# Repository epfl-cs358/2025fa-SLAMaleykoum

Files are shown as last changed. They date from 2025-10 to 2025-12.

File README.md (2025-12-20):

# SLAMaleykoum

> An autonomous mobile robot that transforms an RC car into an intelligent mapping and navigation platform using dual ESP32-S3 microcontrollers.

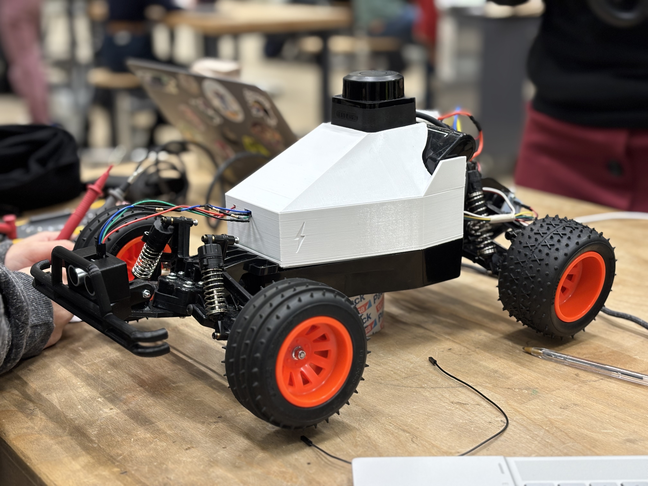
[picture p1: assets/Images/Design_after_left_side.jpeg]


**Live Demo - 19.12.2025**
<p align="center">
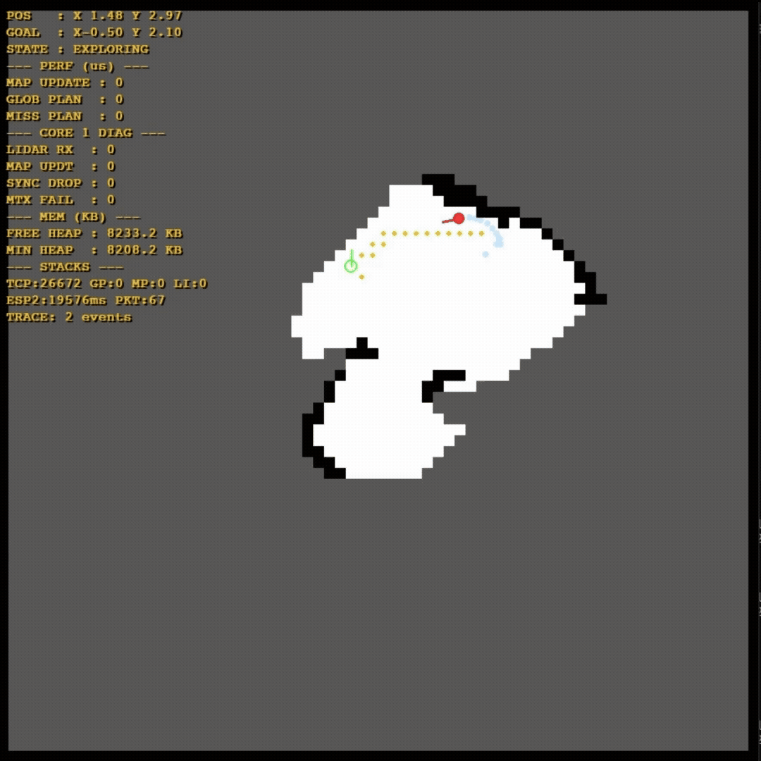
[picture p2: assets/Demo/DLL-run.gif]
  
  
</p>

_Screen recording sped up x3, video in real speed (for reference)_

## Project Context

**Abstract**

SLAMaleykoum aims to implement **Simultaneous Localization and Mapping (SLAM)**, a robotics technique that enables a mobile robot to build a map of an unknown environment while simultaneously tracking its own location within that map. This chicken-and-egg problem requires three core capabilities working in concert:

1. **Mapping**: Building an accurate representation of the environment using LiDAR sensor data processed through a Bayesian occupancy grid with Bresenham ray tracing
2. **Localization**: Determining the robot's position by fusing wheel encoder odometry with IMU orientation data
3. **Navigation**: Planning collision-free paths using A* search on the occupancy grid and executing them with Pure Pursuit trajectory tracking

The system runs entirely on two ESP32-S3 microcontrollers with no external computation, using FreeRTOS for real-time task scheduling. The robot autonomously explores unknown environments, discovers frontiers (boundaries between known and unknown space), and navigates to them while avoiding static and dynamic obstacles detected.

**Course Context:**

This project was developed as part of the [**Making Intelligent Things** (CS-358)](https://edu.epfl.ch/coursebook/en/making-intelligent-things-a-CS-358-A) course at **EPFL** (École Polytechnique Fédérale de Lausanne).

**Acknowledgments:**
- Built upon the physical structrue of [**TurboSLAM**](https://github.com/epfl-cs358/2025sp-turboslam) (previous team)
- Course TAs and [DLL coaches](https://make.epfl.ch/coaches) for guidance and support

**Note on Continued Development:**

Although the CS-358 course has concluded, we continue to actively develop and improve SLAMaleykoum. For current work-in-progress features, planned enhancements, and future research directions, see [Ongoing Works & Next Steps](#ongoing-works--next-steps).

---

## Quick Jump To Detailed Documentation

For in-depth technical details, refer to the dedicated subsystem documentation:

<table>
<tr>
<td width="33%" align="center">

### 🔧 **[Hardware: Step by Step How to build](assets/docs/hardware/ASSEMBLE_GUIDE.md)**

Assembly instructions, wiring diagrams, CAD files, component specs

</td>
<td width="33%" align="center">

### 🗺️ **[ESP-1 Controller: Mapping & Planning](include/esp1/README.md)**

LiDAR processing, Bayesian mapping, frontier detection, A* path planning

</td>
<td width="33%" align="center">

### 🎮 **[ESP-2 Operator: Localization & Driving](include/esp2/README.md)**

Sensor fusion, Pure Pursuit control, motor management, safety systems

</td>
</tr>
</table>

---

## Table of Contents

1. [Project Overview](#project-overview)
2. [Quick Start](#quick-start)
3. [Hardware](#hardware)
4. [System Architecture](#system-architecture)
5. [Software Setup](#software-setup)
6. [Configuration & Tuning](#configuration--tuning)
7. [Documentation Index](#documentation-index)
8. [Archives](#archives)
9. [Ongoing Works & Next Steps](#ongoing-works--next-steps)
10. [Credits](#credits)
11. [Conclusion](#conclusion)

---

## Project Overview

### Vision

SLAMaleykoum is an autonomous robotics platform that transforms a standard RC car chassis into an intelligent mobile robot capable of mapping and navigating unknown environments. The system performs full Simultaneous Localization and Mapping (SLAM), enabling the robot to autonomously explore, build a map, localize itself with high accuracy in real time, navigate to target coordinates, dynamically avoid obstacles, and maintain a reliable estimate of its position throughout the mission.

Here is our original [Project proposal](https://www.overleaf.com/9942875199zgzbkrmgkkkj#3fbbb2) for our SLAM Car. Please note that it represents the initial version of the project. Since then, many aspects have evolved and changed throughout development, so the proposal should be considered an early-stage reference rather than the final design.

### How the Robot "Thinks"

The robot operates through a continuous perception-planning-action loop distributed across two processors:

**High-Level Decision Making (ESP-1 Controller):**
1. **Perceive** - Process LiDAR scans to update the occupancy grid map
2. **Analyze** - Identify frontiers (boundaries between explored and unexplored areas)
3. **Decide** - Select the closest explorable frontier as the next goal
4. **Plan** - Compute a collision-free path to the goal using A* search
5. **Command** - Send path waypoints to the Operator (ESP-2)

**Why this approach?** Frontier-based exploration naturally drives the robot to map the entire environment without human intervention. The robot is "curious" - it always seeks to explore what it doesn't know yet.

**Low-Level Execution (ESP-2 Operator):**
1. **Localize** - Continuously estimate position by fusing encoder and IMU data
2. **Track** - Follow the commanded path using Pure Pursuit controller
3. **React** - Monitor ultrasonic sensor for obstacles; emergency stop if needed
4. **Report** - Send updated position back to Controller for map correction

**Why this split?** The Controller handles computationally expensive tasks (mapping, pathfinding) at lower rates (1-10 Hz), while the Operator focuses on time-critical control loops at high rates (50-100 Hz). This separation ensures smooth, responsive driving even while planning is ongoing.

### Technical Vocabulary

- **ESP** (ESP32-S3): Microcontroller with dual-core processor and WiFi
- **ESC** (Electronic Speed Controller): Motor driver that converts PWM signals to motor power
- **LiDAR** (Light Detection and Ranging): Laser-based distance sensor for environment scanning
- **IMU** (Inertial Measurement Unit): Sensor measuring orientation and acceleration
- **I2C** (Inter-Integrated Circuit): Serial communication protocol for sensors
- **UART** (Universal Asynchronous Receiver-Transmitter): Serial communication between ESPs
- **TCP** (Transmission Control Protocol): Network protocol used for ground station communication
- **GS** (Ground Station): External computer for visualization (monitoring only)

### Key Objectives

- **Autonomous Mapping**: Create detailed environment maps using LiDAR sensor data
- **Robust Localization**: Maintain accurate position estimation through sensor fusion
- **Intelligent Navigation**: Plan and execute collision-free paths to destinations
- **Real-time Control**: Execute precise motor control for path following
- **Remote Monitoring**: Provide GS visualization

> **Important**: The car should be able to operate fully autonomously → with **no** GS.
> No computations nor storage will be offloaded to the GS.

### Core Technologies

- **Hardware**: Dual ESP32-S3 microcontrollers, LiDAR sensor, wheel encoders, IMU
- **Operating System**: [FreeRTOS](https://www.freertos.org/) for real-time multitasking and priority-based scheduling
- **Communication**: UART (inter-processor), TCP (ground station)
- **Algorithms**: 
  - [A* pathfinding](https://en.wikipedia.org/wiki/A*_search_algorithm) - Optimal graph search algorithm
  - [Pure Pursuit](https://www.ri.cmu.edu/pub_files/pub3/coulter_r_craig_1992_1/coulter_r_craig_1992_1.pdf) controller - Path tracking for car-like robots
  - [Bresenham's line algorithm](https://en.wikipedia.org/wiki/Bresenham%27s_line_algorithm) - Efficient grid ray tracing
  - [BFS](https://en.wikipedia.org/wiki/Breadth-first_search) (Breadth-First Search) - Frontier clustering
  - [Bayesian occupancy grid mapping](https://ieeexplore.ieee.org/document/30720) - Probabilistic environment representation

### System at a Glance

```
┌─────────────────────────────────────────────────────────┐
│  ESP-1 CONTROLLER: Mapping & Planning (1-10 Hz)         │
│  • LiDAR processing & Bayesian mapping                  │
│  • Frontier detection & clustering                      │
│  • A* global path planning                              │
│  • Ground station telemetry (WiFi/TCP)                  │
└─────────────────────────────────────────────────────────┘
                         ↕ UART
┌─────────────────────────────────────────────────────────┐
│  ESP-2 OPERATOR: Localization & Driving (50-100 Hz)     │
│  • Sensor fusion (encoder + IMU)                        │
│  • Pure Pursuit path following                          │
│  • Motor & steering control                             │
│  • Emergency obstacle handling                          │
└─────────────────────────────────────────────────────────┘
```

---

## Quick Start

### Prerequisites Checklist

**Hardware:**
- Assembled robot (see [Hardware section](#hardware))
- 9.0V NiMH battery (charged)
- USB-C cables for flashing ESP32s
- Computer with WiFi capability (for visualization)

**Software:**
- [Python 3.8+](https://www.python.org/downloads/)
- [PlatformIO Core](https://docs.platformio.org/en/latest/core/index.html) or VS Code extension ([install guide](https://docs.platformio.org/en/latest/core/index.html))

### Flash & Run

**Step 0: Clone the Repository**
```bash
git clone https://github.com/epfl-cs358/2025fa-SLAMaleykoum.git
cd 2025fa-SLAMaleykoum
```

**Step 1: Install Ground Station Dependencies**
```bash
# Create virtual environment
python3 -m venv slamaleykoum_venv

# Activate environment
source slamaleykoum_venv/bin/activate  # On Windows: slamaleykoum_venv\Scripts\activate

# Install dependencies
pip install -r requirements.txt
```

**Step 2: Flash ESP32 Firmware**

This project uses two ESP32s. You must flash them individually.

```bash
# In VS Code with PlatformIO extension:
# 1. Connect ESP1 via USB (use RIGHT port - left port may not work)
# 2. Open PlatformIO extension (alien icon)
# 3. Click esp1/General/Upload
# 4. Wait for upload to complete
# 5. Repeat for ESP2: Connect ESP2 → esp2/General/Upload
```

**Step 3: Power Up & Connect**

1. **Power sequence:**
   ```
   Battery → ESC → Turn ESC switch ON
   ```
   ⚠️ **WARNING**: When disconnecting, first turn the ESC off, then disconnect the battery.

2. **Connect to robot WiFi:**
   - **SSID:** `LIDAR_AP`
   - **Password:** `l1darpass`

3. **Launch ground station:**
_Note: Further documentation can be found [here](assets/docs/GROUND_STATION.md)_
   ```bash
   # Ensure your venv is active
   source slamaleykoum_venv/bin/activate
   
   # Run the interface
   python ground_station.py
   ```
   A *Pygame* window will appear. Press **START** to begin logging data and visualizing the real-time LIDAR feed.

**What to expect:**
- Ground station shows live LiDAR scan
- Robot begins mapping and moving toward frontiers
- Map builds progressively as robot explores

**First-time issues?** → Check out [Troubleshooting guide](assets/docs/troubleshooting.md)

> *Dev Note: To change WiFi credentials, modify [`src/esp1/main_esp1.cpp`](src/esp1/main_esp1.cpp) before flashing.*

---

## Hardware

### Component List

| Component | Reference Links | Price (CHF) |
|---|---|---|
| Tamiya Blitzer Beetle | [Manual](https://www.tamiyausa.com/media/files/58502ml-829-5367.pdf) | 129.00 |
| RPLIDAR C1 | [Datasheet](https://d229kd5ey79jzj.cloudfront.net/3157/SLAMTEC_rplidar_datasheet_C1_v1.0_en.pdf), [SDK](https://github.com/Slamtec/rplidar_sdk), [Wiki](https://www.waveshare.com/wiki/RPLIDAR_C1) | 79.90 |
| ESP32-S3-WROOM-1 Microcontroller (x2)  | [Datasheet](https://cdn-shop.adafruit.com/product-files/5477/esp32-s3_datasheet_en.pdf) | 50.90 |
| DMS15 Servo | [Wiki](https://wiki.dfrobot.com/DSS-M15S_270%C2%B0_15KG_DF_Metal_Servo_with_Analog_Feedback_SKU__SER0044) | 5.00 |
| BNO086 IMU | [Datasheet](https://docs.sparkfun.com/SparkFun_VR_IMU_Breakout_BNO086_QWIIC/assets/component_documentation/BNO080_085-Datasheet_v1.16.pdf) | 19.90 |
| AS5600 Encoder | [Datasheet](https://files.seeedstudio.com/wiki/Grove-12-bit-Magnetic-Rotary-Position-Sensor-AS5600/res/Magnetic%20Rotary%20Position%20Sensor%20AS5600%20Datasheet.pdf) | 12.90 |
| HC-SR04 Ultrasonic Sensor | [Datasheet](https://handsontec.com/dataspecs/sensor/SR-04-Ultrasonic.pdf) | 2.00 |
| 540J Motor | [Datasheet](https://asset.conrad.com/media10/add/160267/c1/-/en/001385115DS01/adatlap-1385115-540-es-motor-reely-532114c.pdf) | — |
| THW-1060-RTR ESC | [Datasheet](https://www.hobbywing.com/en/uploads/file/20221015/f60b7ebe160a7b283927ae8916d36763.pdf) | — |
| LM2596 Buck Converter | [Datasheet](https://www.ti.com/lit/ds/symlink/lm2596.pdf) | 5.90 |
| 7.2V Battery | [Product Page](https://www.galaxus.ch/fr/s5/product/gens-ace-modelisme-dune-batterie-720-v-5000-mah-batterie-rc-9459930) | 32.90 |
| **Total Cost** | | **338.4**  |

**Additional materials needed:**
- $3 \times 1 K\Omega$ resistors (for the ultrasonic sensor voltage divider)
- Assorted jumper cables and connectors (male/female)
- Heat-shrink tubing or insulation sleeves
- Soldering kit (soldering iron, solder wire)
- Hot air/heat gun (for shrinking tubing)
- Screw set (M3 and M6 as used in mounts)

### Assembly Overview
Clicky link: [Full Step-by-step Assembly guide here](/assets/docs/hardware/ASSEMBLE_GUIDE.md)

The robot is built on a Tamiya Blitzer Beetle chassis with custom 3D-printed mounts for the LiDAR, ESP32 boards, encoder, ultrasonic sensor, and battery. Assembly is straightforward: build the base chassis, install the encoder and magnet on the motor shaft, mount the electronics platform, attach the sensors, and finish with wiring.

**Assembly phases:**
1. **Chassis** - Build base chassis & install motor/encoder
2. **3D-printed mounts** - Install LiDAR platform, ESP32 holders, sensor brackets
3. **Electronics mounting** - Secure ESPs, buck converter, IMU
4. **Wiring** - Follow electrical diagram, install voltage divider
5. **Final assembly** - Install battery, route cables, verify connections

**📘 Full step-by-step assembly guide (with photos, CAD files, wiring diagrams):**  
→ [**Complete Assembly Instructions**](/assets/docs/hardware/ASSEMBLE_GUIDE.md)

### Wiring & Electrical

Clicky link: [Full wiring explanation HERE](/assets/docs/hardware/circuit/README.md)

**Electrical Diagram:**

<p align="center">
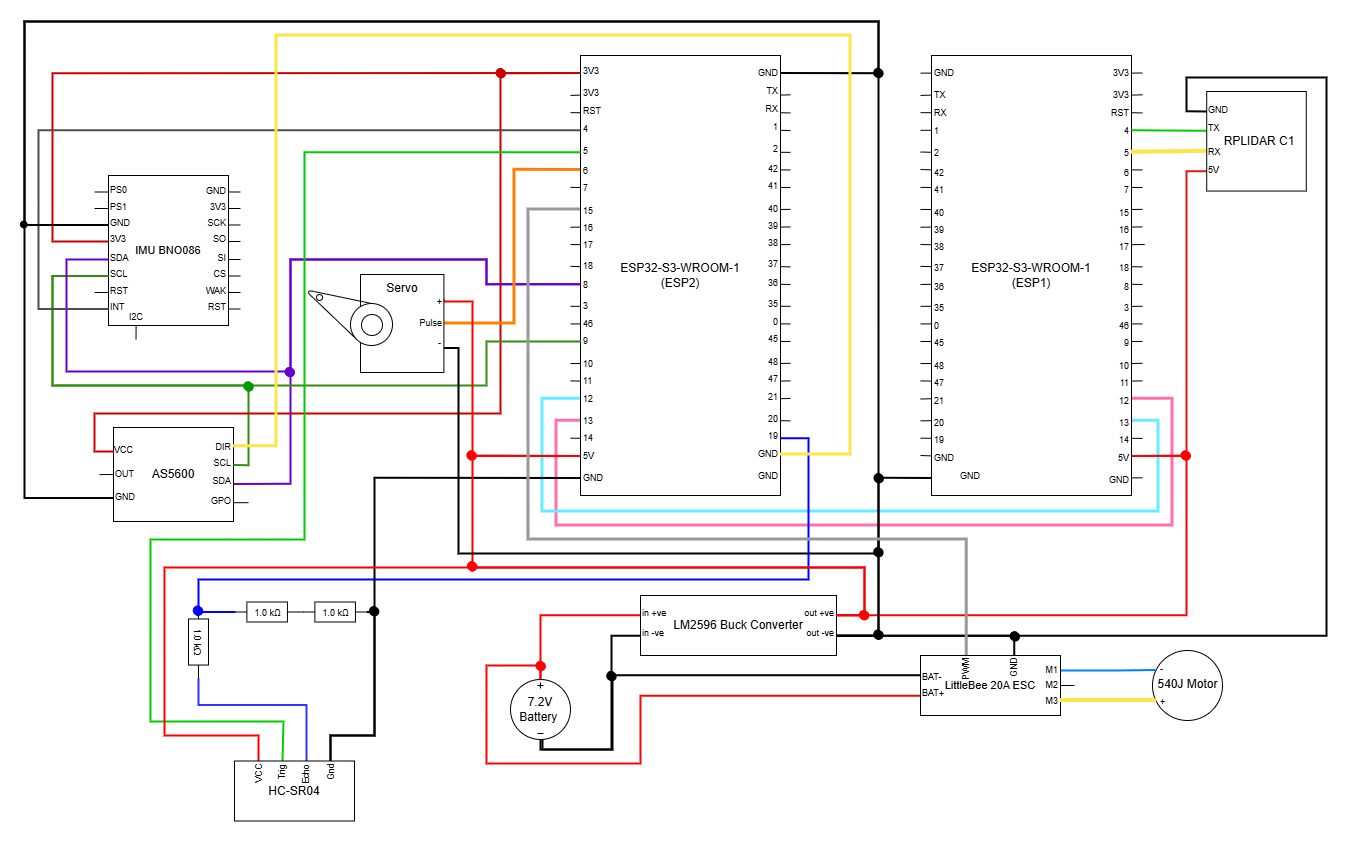
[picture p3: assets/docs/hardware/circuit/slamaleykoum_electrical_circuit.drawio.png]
Electrical Circuit
  
</p>

**⚠️ Important Wiring Notes (Do Not Skip)**

- **Common Ground**: All components (ESP32s, ESC, sensors, servo) must share a common ground from the buck converter.

- **5V vs 3.3V Power**:
  - ESP32 boards, ultrasonic sensor, lidar, and servo are powered from 5V (buck converter)
  - IMU and encoder are powered from ESP2's 3.3V pin

- **Ultrasonic Sensor (HC-SR04) → Voltage Divider Required**
  - The HC-SR04 ECHO pin outputs 5V
  - ESP32 GPIOs are 3.3V-only
  - A resistor voltage divider is mandatory on the ECHO line
  - Connecting ECHO directly to the ESP32 will damage the GPIO

- **ESP-to-ESP Communication**: UART cross-connection is required (TX ↔ RX between ESP1 and ESP2).

**📘 Detailed Wiring & Soldering Guide:**  
→ [**Full wiring explanation**](/assets/docs/hardware/circuit/README.md)

### CAD Files

You can explore all STL files directly in the [**CAD folder**](/assets/CAD).

Here is a quick video of the car's body and roof: [**CAD Video**](/assets/docs/hardware/CAD/fast_cad_video.mp4)



**Note:** The CAD files for the **front bumper**, **ultrasonic sensor case**, and **encoder mount** were originally designed by the group from whom we inherited the car, [**TurboSLAM**](https://github.com/epfl-cs358/2025sp-turboslam).

**Before implementing the hardware setup**, check the [Problems and Recommendations](assets/docs/troubleshooting.md) section (Hardware parts) to get a full scope of what may need to be modified.

---

## System Architecture

The computational load is divided between two ESP32-S3 microcontrollers with clearly defined roles:

- **ESP-1 (Controller)**: High-level perception and planning
- **ESP-2 (Operator)**: Low-level control and execution

We use **FreeRTOS** to enable parallel task execution with priority-based scheduling, ensuring time-critical control loops run reliably while computationally expensive planning tasks run in the background. Inter-processor communication happens via **UART** serial links.

**Rationale:**

1. **Performance**: Each processor focuses on its task without competing for resources
2. **Modularity**: Components are well-isolated, making testing and debugging easier
3. **Reliability**: Control loop continues operating even if global planning encounters issues
4. **Efficiency**: Only essential data is sent from one ESP to the other, limiting information flow
5. **Parallelism**: FreeRTOS allows multiple tasks with different priorities to run concurrently on each dual-core ESP32

*Note: For each ESP we've got a dedicated README file delving into more details. They can be found in [`include/esp1/README.md`](include/esp1/README.md) and [`include/esp2/README.md`](include/esp2/README.md)*

### Architecture Diagrams

**ESP-1 System Diagram:**
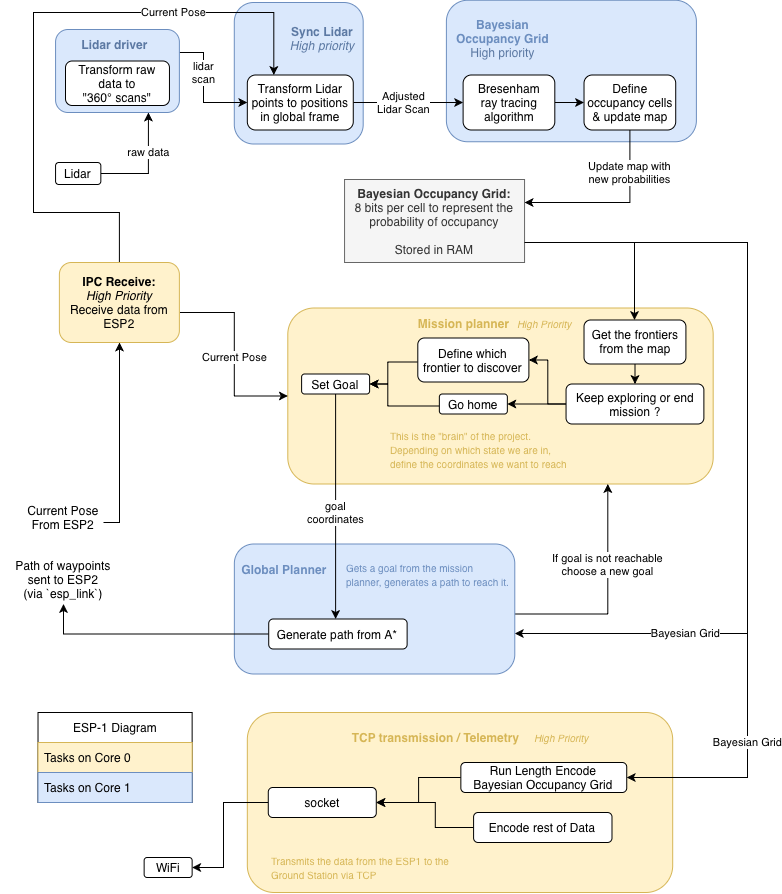
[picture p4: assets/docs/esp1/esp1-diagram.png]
ESP-1 Architecture


**ESP-2 System Diagram:**
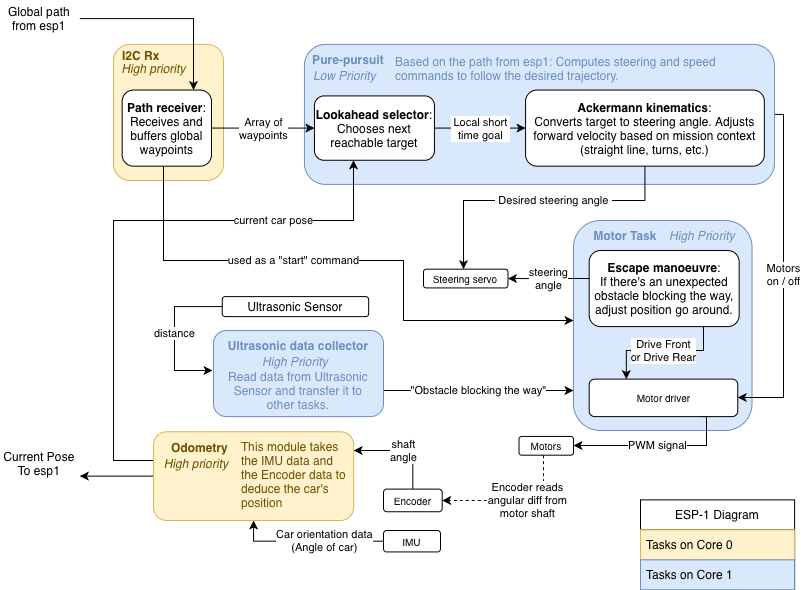
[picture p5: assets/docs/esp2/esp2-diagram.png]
ESP-2 Architecture


### ESP-1 Controller: Mapping & Planning

🦄 **[Full ESP-1 Documentation →](include/esp1/README.md)**

**Primary Mission**: Create and maintain a global understanding of the environment and plan high-level navigation strategies.

**Core Responsibilities**:
- Generate and maintain occupancy grid maps using Bayesian updates
- Find the frontier cells to explore and cluster them using BFS algorithms
- Define a temporary goal for the car to reach
- Plan global paths using A* algorithm
- Share telemetry with ground station via WiFi (visualization purposes)
- Send the computed path to ESP-2

**Key Components:**
- **LiDAR Processing**: Extract and convert RPLIDARC1 data into readable scans
- **Bayesian Grid Mapping**: Build persistent 2D occupancy grid from LiDAR data
- **Mission Planner**: Select exploration goals based on frontier detection
- **Global Planner (A*)**: Compute collision-free paths on the grid

**Operating Frequency**: 1-10 Hz

### ESP-2 Operator: Localization & Motion Control

🦄 **[Full ESP-2 Documentation →](include/esp2/README.md)**

**Primary Mission**: Execute precise vehicle control and maintain high-frequency local position tracking.

**Core Responsibilities**:
- Execute Pure Pursuit path following algorithm
- Handle emergency stop commands and maneuvers to escape when stuck
- Aggregate sensor data (odometry, IMU) to track the position of the car and forward to ESP-1

**Key Components:**
- **Sensor Fusion**: Combine encoder + IMU for pose estimation
- **Pure Pursuit Controller**: Local path-tracking with bicycle model
- **Motor Control**: ESC PWM control with emergency stop
- **Safety System**: Ultrasonic-based obstacle detection
- **Recovery Maneuvers**: Automated escape sequences when blocked

**Operating Frequency**: 50-100 Hz

### Communication Architecture

#### Inter-ESP Communication (UART)

**Protocol**: Custom packet-based with checksums

**Data Flow:**

| Direction | Message Type | Content |
|---|---|---|
| ESP-2 → ESP-1 | `Pose2D` | Current car's position (x, y, θ) |
| ESP-1 → ESP-2 | `PathMessage` | Global path waypoints |

👉 **[Full ESP Link Protocol Documentation →](include/common/esp_link_readme.md)**

#### Ground Station Communication (WiFi/TCP)
🦄 **[Full GS Documentation →](include/esp2/README.md)**

**WiFi Mode**: Access Point (AP)
```
SSID:     LIDAR_AP
Password: l1darpass
```

**ESP-1 → Ground Station**:
- Real-time map visualization data
- Mission status: goal and state
- Robot pose and trajectory
- Telemetry logs

The ESP1 creates a Wi-Fi access point (AP) that we connect to for **monitoring purposes only**. We used MQTT at first to get feedback during tests, but quickly switched to TCP, as it supports higher data throughput.
We additionally log the CPU profiling for the esp1 for debugging pourpuses. Detailed information: [CPU Profiling Documentaiton](assets/docs/debugging/CPU_PROFILING.md)

If you want to establish the same MQTT connection to debug, here is the guide to follow: [**WiFi and MQTT connection guide**](/assets/docs/WiFi_and_MQTT_Connection_Guide___SLAMaleykoum.pdf).

### Shared Mechanisms (`common/`)

- `data_types.h`: Definitions of shared data structures
- `esp_link.h`: The communication system from one ESP to the other. [→ ESP Link README](include/common/esp_link_readme.md)
- `transforms.h`: Functions that transform the position of the robot to the grid and the other way around. [→ Transforms README](include/common/transforms_readme.md)
- `utils.h`: Regroups the functions used across different files to avoid redefining it.
- `wifi_connection.h`: Protocol to connect the WiFi for MQTT

---

## Software Setup

### Development Environment

**Prerequisites:**
* [Python 3.8+](https://www.python.org/downloads/)
* [PlatformIO Core](https://docs.platformio.org/en/latest/core/index.html) or VS Code extension

### Project Structure
```
SLAMaleykoum/
├── include/                    # Header files
│   ├── common/                 # Shared utilities & communication
│   ├── esp1/                   # Mapping & Planning headers
│   └── esp2/                   # Localization & Control headers
│
├── src/                        # Implementation files
│   ├── common/                 # Shared utilities
│   ├── esp1/                   # ESP-1 source code
│   └── esp2/                   # ESP-2 source code
│
├── assets/                     # Documentation & media
│   ├── Demo/                   # Demo videos
│   ├── Images/                 # Photos & diagrams
│   └── docs/                   # Technical documentation
│       ├── hardware/           # Assembly guide, CAD files, wiring
│       ├── esp1/               # Architecture diagrams
│       └── esp2/               # Architecture diagrams
│
├── archives/                   # Historical deprecated implementations
│
├── README.md
├── requirements.txt            # Set up python requirements
├── ground_station.py           # Visualization & telemetry
├── platformio.ini              # Build configuration
└── boards/                     # Custom board definitions
```

**Key Directories:**
- `include/` + `src/` - Dual-ESP codebase organized by subsystem
- `assets/` - All documentation, images, and demo videos
- `archives/` - Previous implementations and test code

### Ground Station (PC)

The ground station script runs on your computer to visualize telemetry.  
*Note: We recommend using a virtual environment.*

Install the dependencies from our `requirements.txt` file.

```bash
# Create virtual environment
python3 -m venv slamaleykoum_venv

# Activate environment
source slamaleykoum_venv/bin/activate  # On Windows: slamaleykoum_venv\Scripts\activate

# Install dependencies
pip install -r requirements.txt
```

### Firmware (ESP32s)

This project uses two ESP32s. You must flash them individually.

**Upload Code:**

Open in PlatformIO: Open the project folder in VS Code.

1. Connect to the ESP1 via USB.
2. Open the *platformio* extension in VS Code (the alien icon).
3. Click on `esp1/General/Upload`.
4. Repeat for the ESP2: Connect ESP2 → `esp2/General/Upload`.

**⚠️ Important:** Use the **RIGHT USB port** on each ESP32. Left ports don't seem to work for programming.
*Note: In our design, the esp1 is upside down, so the right port is the one on the left looking from the outside of the car.*

### WiFi Configuration

**Default credentials** (edit before flashing if needed):
```cpp
#define WIFI_SSID "LIDAR_AP"
#define WIFI_PASSWORD "l1darpass"
```

---

## Configuration & Tuning

### Map Parameters

Configure the mapping grid size and resolution:

```cpp
// src/esp1/main_esp1.cpp
#define GRID_SIZE_X 70      // cells
#define GRID_SIZE_Y 70      // cells
#define RESOLUTION 0.2      // meters/cell <- This is the most important parameter.
                            // It directly affects the size of the grid.
```

**Physical map size:** 14m × 14m (with 0.2m resolution)
**Memory usage:** 70 × 70 × 1 byte = 4.9 KB

**⚠️ Important:** Grid dimensions **must match** in [`ground_station.py`](ground_station.py):
```python
GRID_SIZE_X = 70
GRID_SIZE_Y = 70
RESOLUTION = 0.2
```

**Trade-offs:**
- Larger `RESOLUTION` → bigger mapping area → less detail
- Smaller `RESOLUTION` → smaller mapping area → more detail
- Larger grid → more detail, more memory, slower updates
- Smaller grid → less detail, faster, but limited range

### Control Parameters

```cpp
// include/esp2/control/pure_pursuit.h
#define LOOKAHEAD_DISTANCE 0.3   // meters
#define TARGET_SPEED 0.2         // m/s
#define WAYPOINT_THRESHOLD 0.1   // meters
#define MAX_STEERING_ANGLE 30    // degrees
```

**Tuning guide:**
- `LOOKAHEAD_DISTANCE`:
  - Too small → oscillation, sharp turns
  - Too large → cuts corners, misses waypoints
- `TARGET_SPEED`:
  - Higher → faster exploration, worse odometry, worse mapping
  - Lower → accurate mapping, slow mission

### Sensor Parameters

```cpp
// include/esp2/hardware/encoder.h
#define ENCODER_TICKS_PER_REV 4096
#define GEAR_RATIO 10.0
#define WHEEL_RADIUS 0.032       // meters

// include/esp2/hardware/imu.h
#define IMU_SAMPLE_RATE 100      // Hz
#define YAW_STABILITY_THRESHOLD 15  // degrees

// include/esp2/hardware/ultrasonic.h
#define EMERGENCY_THRESHOLD 0.2  // meters
#define ULTRASONIC_TIMEOUT 30    // ms
```

### FreeRTOS Task Priorities

```cpp
// ESP-1
Lidar_Read_Task:       Priority 4, Core 1, Stack 3072
Lidar_Sync_Map_Task:   Priority 4, Core 1, Stack 8192
Bayesian_Grid_Task:    Priority 3, Core 1, Stack 20480
IPC_Receive_Task:      Priority 3, Core 0, Stack 2048
TCP_Transmit_Task:     Priority 1, Core 0, Stack 8192
Mission_Planner_Task:  Priority 2, Core 0, Stack 4096
Global_Planner_Task:   Priority 2, Core 0, Stack 8192

// ESP-2
TaskReceivePath:       Priority 3, Core 0, Stack 6144
TaskOdometryUnified:   Priority 3, Core 0, Stack 10240
TaskMotor:             Priority 2, Core 1, Stack 6144
TaskUltrasonic:        Priority 2, Core 1, Stack 6144
TaskPurePursuit:       Priority 1, Core 1, Stack 6144
```

---

## Documentation Index

### Core System Documentation

**Main System:**
- [Main README](README.md) - This document
- [Project Proposal](https://www.overleaf.com/9942875199zgzbkrmgkkkj#3fbbb2) - Original project vision

**ESP Subsystems:**
- [ESP-1: Mapping & Planning](include/esp1/README.md)
- [ESP-2: Localization & Control](include/esp2/README.md)

### Software Documentation
- [ESP-1: Mapping & Planning](include/esp1/README.md)
- [ESP-2: Localization & Control](include/esp2/README.md)
- [Ground station](assets/docs/GROUND_STATION.md)
- [Pure Pursuit Controller](include/esp2/control/pure_pursuit_readme.md)

### Hardware Documentation

**Assembly & Build:**
- [Complete Assembly Guide](/assets/docs/hardware/ASSEMBLE_GUIDE.md)
- [Wiring & Circuit Details](/assets/docs/hardware/circuit/README.md)

**Shared Utilities:**
- [ESP Link Protocol](include/common/esp_link_readme.md)
- [Coordinate Transforms](include/common/transforms_readme.md)

### Configuration & Setup

- [WiFi & MQTT Setup Guide](/assets/docs/WiFi_and_MQTT_Connection_Guide___SLAMaleykoum.pdf)

### Debugging & Development Tools

- [CPU Usage Profiling Guide](/assets/docs/debugging/CPU_PROFILING.md)
- [Troubleshooting Guide](assets/docs/troubleshooting.md)
---

## Archives

The purpose of this directory is to save our previous work, and keep track of the tests we made.

### Previous Work

We tried many things that were eventually not used. These can be found in the subdirectories of `esp1` and `esp2`.

#### `esp1`
- `rpLidar` (and `rpLidarTypes`) contains the full KKest library as found on GitHub. While we kept the same underlying implementation, we simplified it in our codebase to reduce memory usage. The original version is kept here for reference.

#### `esp2`
- `motor_pid` was ultimately not functional due to the poor quality of the ESC we used.
- `ekf_localizer` was not used because the IMU was not accurate enough for acceleration_y and acceleration_x so the computation of the position using IMU was unreliable.
- `pure_pursuit` is used in the project, but the archived files contain earlier implementations based on EKF and PID control. We kept the full version here for reference, while a cleaned and correct implementation is used in the main code.
- `recovery_maneuver` turned the car toward the first waypoint of a path. Not used due to delays with new paths; current version does an automatic 180° turn for reliability. We kept this improved version in the archive.

### The Tests

Some tests are no longer directly runnable without modifications, as data types evolved over time and the include paths differ from the current project structure.

There is one test directory per ESP, containing all the tests developed throughout the project. Some tests target specific components, while others exercise the full system.

To avoid redefining the same constants and parameters in every test, two shared files are used:
`test_common_esp<i>` contains constants and the prototypes of the setup and loop functions, and `test_globals_esp<i>` defines and initializes global variables.

Each test entry point is implemented in `test_main_esp<i>`, which simply includes these shared files. In the setup and loop functions of the test main, the test to run is selected via a test ID.

The Python files are used for TCP monitoring and for displaying the received data in a structured format.

### Development & Debugging Tools

During development, we created custom CPU profiling tools to analyze FreeRTOS task performance:
- Task execution timeline tracking
- CPU usage per core
- Mutex contention analysis

See [CPU Profiling README](assets/docs/debugging/CPU_PROFILING.md) for implementation details.

---

## Ongoing Works & Next Steps

This project continues to evolve beyond the course timeline (Automn Semester 2025). Below are the improvements and features currently in development or planned for future implementation.

### Improvements

**Hardware Upgrades:**
- Replace THW-1060-RTR ESC with IBT-4 (BTS7960) motor driver for smooth PWM control and enable PID velocity control
- Replace current wireing with a proper printed circuit board (PCB)

**Software Enhancements:**
- Switch from TCP to UDP since we don't care about dropping packets
- Test the PID velocity controller (currently blocked by ESC limitations)
- Improvements of the Path Planning algorithm to take into account non-holonomic constraints
- Improve the Goal Definition to better handle complicated goals to reach
- Add drift correction using LiDAR scan matching (Something similar to [this](https://static.googleusercontent.com/media/research.google.com/en//pubs/archive/45466.pdf))
- Optimize Bayesian grid update performance with [Single Instruction, Multiple Data (SIMD)](https://en.wikipedia.org/wiki/Single_instruction,_multiple_data) operations
- Test adaptive lookahead distance in Pure Pursuit based on current speed

**System Robustness:**
- Implement formal state machine for mission control
- Resume development of the CPU analysis/testing
- Develop comprehensive unit test suite with hardware-in-the-loop testing
- Battery voltage monitoring with low-power warnings

### Known Issues to Address 🐛

- Odometry drift due to encoder noise and IMU drift
- Occasional A* failures in highly cluttered environments

**Current Focus**: Replacing the ESC and implementing PID velocity control (expected completion: February 2026)

---

## Credits

#### Project Team

SLAMaleykoum was develeped as part of the [**Making Intelligent Things** (CS-358)](https://edu.epfl.ch/coursebook/en/making-intelligent-things-a-CS-358-A) course at **EPFL** (École Polytechnique Fédérale de Lausanne). Building on the foundation laid by the [**TurboSLAM**](https://github.com/epfl-cs358/2025sp-turboslam) team who designed the original electrical circuit, encoder mount, and ultrasonic sensor case.

#### Use of AI Tools in Development

This project was developed with the assistance of AI-powered development tools, in accordance with EPFL's academic integrity guidelines.

**AI Tools Used:**
- **Claude (Anthropic)** & **Gemini Pro (Google)**: Code debugging, algorithm optimization, and technical documentation

**Scope of AI Assistance:**

**AI Assisted With:**
- Optimizing Bayesian grid updates and A* search
- Code review and identifying edge cases
- Structuring documentation and improving technical writing
- Troubleshooting hardware integration issues (encoder noise, IMU drift, ESC limitations)

**AI Did NOT:**
- Define project goals or system architecture
- Make engineering decisions or trade-off evaluations
- Perform hardware assembly, wiring, or physical testing
- Collect experimental data or validate performance in real-world conditions

**Validation:** All AI-generated code was manually reviewed, tested on actual hardware, and adapted to meet project-specific constraints.

**Team Contribution:** Core system design, algorithmic implementation, hardware integration, and experimental validation were performed by the project team. AI tools accelerated development but **did not** replace the hands-on engineering work, domain expertise, and hundreds of hours of testing and debugging required to build a working autonomous robot.

#### Key Technologies & Libraries

- **FreeRTOS** - Real-time operating system for multitasking
- **Rob Tillaart's AS5600 library** - Magnetic encoder reading
- **RPLIDAR C1 SDK** - Slamtec's LiDAR interface
- **PlatformIO** - Development platform for ESP32
- **Python + Pygame** - Ground station visualization

#### Hardware Credits

- **Tamiya Blitzer Beetle** - RC car chassis platform
- **TurboSLAM Team** - Original design of the electrical circuit, and original CAD designs for bumper, ultrasonic case, and encoder mount

---

## Conclusion

SLAMaleykoum demonstrates the transformation of a standard RC car into a fully autonomous robot capable of real-time mapping, localization, and navigation. By distributing computation across two ESP32-S3 microcontrollers and leveraging FreeRTOS, the system achieves a robust, modular, and fully self-contained architecture.

The project involved addressing multiple hardware and software challenges, leading to practical design choices and algorithmic optimizations suited to embedded constraints. Overall, SLAMaleykoum provides a solid foundation for future improvements and stands as a complete and extensible SLAM platform for autonomous robotics on resource-limited hardware.

---

**Questions? Issues? Feedback?**

For technical support or to report issues, please refer to the [Troubleshooting](assets/docs/troubleshooting.md) section first. For further assistance, consult the detailed component documentation in the [Documentation Index](#documentation-index).

_For any further questions or feedback, contact santiago.silva-carrillo@epfl.ch_

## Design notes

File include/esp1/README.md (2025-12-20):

🏠 [Backlink to the main README](/README.md)

# ESP-1: Mapping & Global Planning Module
ESP-1 is responsible for the **global understanding** of the robot's environment and mission. It maintains the authoritative map, and makes high-level navigation decisions. Operating at lower frequencies (1-10 Hz) but with higher computational complexity.

>**Core Mission**: Build accurate map depending on the position given by ESP-2, decide where to go next.

## architecture diagram
Here is the current architecture.
ESP-1 Diagram

---

## Hardware
### Lidar :
- **Goal**: Extract the LiDAR points from the Serial2 buffer and convert them into readable data for Bayesian Grid.

- **Input**: Raw LiDAR data bytes (from RPLIDARC1).

- **Process**: Each raw point of 5 bytes is converted into a LiDAR point containing : an angle (in degrees), a distance (in millimeters), a quality (between 0 and 255).
Then, we put all the points of a "scan" (which corresponds to a 360° turn of the LiDAR) into a `LiDARScan`, which contains each points, the count of the scan and a timestamp to know when the scan has been calculated.

- **Output**: `LiDARScan` with a maximum of 500 points.

## Mapping
### The Bayesian Grid :

The **BayesianOccupancyGrid** class implements a 2D log-odds occupancy grid for building a persistent map of the environment from LiDAR data on an ESP32.

Each grid cell stores an **int8 log-odds** value, clamped between predefined bounds, representing the belief that the cell is occupied.

**Bayesian Occupancy Grid Update**
- **Input**:
     A `SyncedScan` containing :
     - The Global `Pose2D` of the car from ESP-2.
     - A full `LiDARScan` data (distances, angles and qualities).

- **Strict input validation**:
     - Rejects NaN or infinite pose, angles, or coordinates
     - Ensures bounded angle normalization
     - Skips updates if the robot pose is outside valid grid bounds

- **Ray tracing**:
     - Applies a Bresenham line algorithm from the robot position to the hit point
     - Traversed cells are updated as free space
     - The final hit cell is updated as occupied only if the measurement is within valid range

- **Log-odds update**:
     - Free cells: additive negative log-odds update
     - Occupied cells: additive positive log-odds update
     - Values are clamped to predefined minimum and maximum limits

- **Real-time safety**:
     - A watchdog aborts the update if processing exceeds a fixed time budget (100 ms)

- **Output**: 
     - A grid of size `size_x × size_y` and of resolution `grid_resolution` (meters per cell). This grid is the dense, persistent map used by the Global Planner to find collision-free paths to the mission goal.

## Planning
### Mission Planner :
The **MissionPlanner** module selects high-level exploration goals based on the current Bayesian occupancy grid and robot state.
It bridges the gap between mapping and global path planning.

- **Finding the frontiers**: 
     - A **frontier** is defined as a free cell (`p ≤ FREE_BOUND_PROB`) that has at least one unknown neighbor (`FREE < p < OCC`).
     - Frontier detection uses 4-connected neighbors.
     - The planner first searches for frontiers near the robot, then expands to the full map if none are found.

- **Frontier Clustering**:
     - Adjacent frontier cells are grouped into clusters using a BFS algorithm.
     - Each cluster stores:
          - Size
          - Centroid
          - First discovered frontier cell (fallback)
     - Clusters smaller than `MIN_CLUSTER_SIZE` are discarded.

- **Goal Selection**: 
     - Among valid clusters, the planner selects the closest sufficiently large cluster.
     - If the cluster centroid lies in an unsafe or unknown cell, the planner falls back to the first frontier point.
     - A safety padding step ensures the final goal is surrounded by free space, accounting for the robot’s physical radius

- **Safety and Validity Checks**:
     - Goals are rejected if:
          - They overlap occupied or unknown cells
          - They violate robot clearance constraints
          - They are listed in the invalid-goal blacklist
     - The planner continuously verifies whether the current goal is still valid as the map evolves.

- **Failure Handling and State Management**:
     - The planner operates in two modes:
          - `EXPLORATION_MODE` (default)
          - `RETURN_HOME`
     - If no valid frontiers are found:
          - The planner waits and retries for a limited number of cycles
          - A patience counter prevents premature failure at startup
     - After repeated failures, the planner switches permanently to `RETURN_HOME`

- **Output**:
     - The planner outputs a MissionGoal, containing:
     - Target pose (world coordinates)
     - Mission type
     - This goal is consumed by the GlobalPlanner for path computation.

**D. GlobalPlanner (A\*)**

The **GlobalPlanner** module computes a global, grid-based path on a Bayesian occupancy grid using a constrained A*-style search.
It is designed to be deterministic, memory-safe, and suitable for real-time embedded systems.

- **Input**: The `BayesianOccupancyGrid`, the `MissionGoal` (the target coordinates) and the `Pose2D` of the car. The `GlobalPlannerWorkspace` is a pre-allocated memory buffer that stores A* state.

- **Process**: 
     1. Coordinate conversion
          - Start and goal poses are converted from world coordinates to grid indices.
          - Planning aborts if either lies outside the grid or on invalid cells.
     2. A*-style search
          - Search is performed on a 4-connected grid (no diagonal motion).
          - Movement cost g(n) is uniform for each grid step.
          - Heuristic h(n) is a weighted Manhattan distance, favoring straighter paths over strict optimality.
          - The heuristic is intentionally non-admissible for faster convergence.
     3. Collision and clearance handling
          - Cells are rejected if occupied or unknown.
          - Additional safety buffering is enforced: a cell is considered invalid if any of its 8 neighbors is occupied or unknown.
          - This implicitly inflates obstacles to preserve clearance around walls.
     4. Search limits
          - The search enforces strict limits on:
               - Maximum grid size
               - Priority queue size
               - Total A* iterations
          - If any limit is exceeded, planning fails gracefully.

- **Path Reconstruction**:
     - Parent indices are stored during search.
     - The path is reconstructed from goal to start and reversed.
     - If the full path exceeds `MAX_PATH_LENGTH`, it is downsampled while preserving start and end points.

- **Output**: 
     - A list of coordinates, packaged as a `PathMessage` (a vector of `Waypoint` structs).
     - If no valid path is found, an empty path message is returned.
     - The path is forwarded to the UART sender task on ESP-1.

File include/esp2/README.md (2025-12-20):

🏠 [Backlink to the main README](/README.md)

# ESP-2: Real-Time Control & Actuation Module

ESP-2 is dedicated to real-time execution, low-latency control, and sensor management.
It operates at a high frequency (50-100 Hz) to ensure stable actuation and precise velocity tracking.

> **Core Mission**: Execute the global path plan stably, maintain smooth velocity control, and gather high-frequency sensor data for both local and global localization.

## architecture diagram
_Here is the current architecture._


## Hardware

### Servo :
Control the steering angle of the car.

- **Input**: Desired steering angle (in degrees).
- **Process**: The servo is initialized and attached to the specified GPIO pin. At startup, it is set to a neutral position (110°). During operation, the target angle is sent directly to the servo, which updates its position accordingly. The current angle is stored internally for state tracking.
- **Output**: Steering angle applied to the servo (in degrees).

### Encoder :
Measure the car’s velocity and traveled distance using a magnetic encoder.

- **Input**: Raw angular position data from the AS5600 magnetic encoder via I2C.
- **Process**: The encoder provides motor shaft angular velocity and cumulative position. Motor speed is converted to wheel angular velocity using the gear ratio, then to linear velocity using the wheel radius. The angular velocity can be filtered before conversion to have more stability. The cumulative encoder position is tracked over time and converted into a total traveled distance by integrating incremental wheel rotations. Accurate distance estimation requires frequent polling.
- **Output**: Motor angular velocity, wheel angular velocity, linear velocity, and cumulative traveled distance (in meters).

### I2C Mutex and Wire :
Provide safe and shared access to the I2C bus across multiple components.

- **Input**: I2C read/write requests from multiple sensors and peripherals.
- **Process**: A global FreeRTOS mutex (i2c_mutex) is used to protect all I2C transactions and prevent concurrent access to the bus. Each component locks the mutex before performing I2C operations and releases it afterward.
A single shared TwoWire instance (I2C_wire) is used by all devices to ensure consistent I2C configuration and avoid multiple bus initializations.
- **Output**: Thread-safe and reliable I2C communication for all connected sensors.

### IMU :
Measure the orientation of the car to provide inertial information for state estimation and control.

- **Input**: Raw 9-Axis IMU Readings (Gyro, Accelerometer, Magnetometer).
- **Process**: The IMU is polled at a fixed rate and raw sensor reports are converted into physical quantities. Only the quaternion output is enabled and kept, as it is the only representation that provides reliable data in our setup. These values are stored in a compact IMUData structure and timestamped for later use. No full sensor fusion or localization is performed at this stage.
- **Output**: IMUData containing quaternion orientation and timestamps.

### Motor :
Control the car’s DC motor through the ESC, with low-level PWM handling and high-level motion commands.

- **Input**: Desired motor command (power level or direction).
- **Process**: The MotorController handles low-level ESC control by generating PWM signals. It converts target power levels into pulse widths and applies smooth ramping to avoid sudden changes. An emergency stop immediately sets the ESC to neutral.
The MotorManager provides a higher-level interface built on top of the controller, exposing simple commands such as forward, backward, stop, and emergency stop. It manages direction and power scaling and periodically updates the controller to gradually reach the target speed.
- **Output**: PWM signal sent to the ESC, resulting in controlled motor speed and direction.

### Ultrasonic : 
Sensor used to detect close obstacles in front of the car for safety and emergency handling.

- **Input**: Raw signals from the trigger and echo pins of the ultrasonic sensor.
- **Process**: A trigger pulse is sent, and the echo return time is measured to compute the distance to the obstacle. This distance is continuously monitored and compared against a safety threshold. When an obstacle is detected too close, an emergency stop is triggered and a recovery maneuver can be initiated.
- **Output**: Distance to the nearest obstacle.

## Control

### Pure Pursuit (`pure_pursuit.h`):

[Open Pure Pursuit README](/include/esp2/control/pure_pursuit_readme.md)

Local path-tracking controller responsible for converting global waypoints into low-level steering and speed commands.

- **Input**: `PathMessage` (waypoints) from ESP-1 and robot current pose
- **Process**: selects a lookahead point on the path and computes the steering command using the Pure Pursuit bicycle model
- **Output**: steering angle and target speed commands sent to the motor and steering hardware

### Recovery Maneuvers :

- **Input**: `Current vehicle pose` for yaw estimation.    Global motor and steering interfaces (`MotorManager`, `DMS15`).
- **Process**: Move backward briefly to create clearance from obstacles. Perform a sequence of alternating backward and forward motions : steer wheels to opposite angles (left/right) during each motion.  
Insert short pauses to stabilize the vehicle and reduce mechanical stress
Repeat the sequence a fixed number of times to achieve an approximate quarter-turn

- **Output**: Vehicle reoriented to face approximately an opposite direction.
Motors stopped and steering centered, ready to resume normal navigation.

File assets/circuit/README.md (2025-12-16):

# SLAM Car Electrical Diagram

<p align="center">
  Electrical Circuit
</p>

## Quick Recap

This diagram represents the electrical circuit of our project.  
The colors mostly match the real car wiring, with a few adjustments made for clarity and visibility.

### Adjustements: 
- **ESP-to-ESP communication cables** are shown in pink/blue (real life: black) to avoid confusion with ground.  
- **ESC PWM to ESP2 pin 15** is shown in grey (real life: white) to make it stand out clearly.  

## Detailed explaination of the wiring

#### Power Connections

- **Battery Power Split**:  
  Solder a 2‑PIN JST male connector to the 7.2V battery.  
  This battery powers the ESC and also supplies input to the buck converter.  
  Connect the black wire to the converter’s VIN (–) and the red wire to VIN (+).

<p align="center">
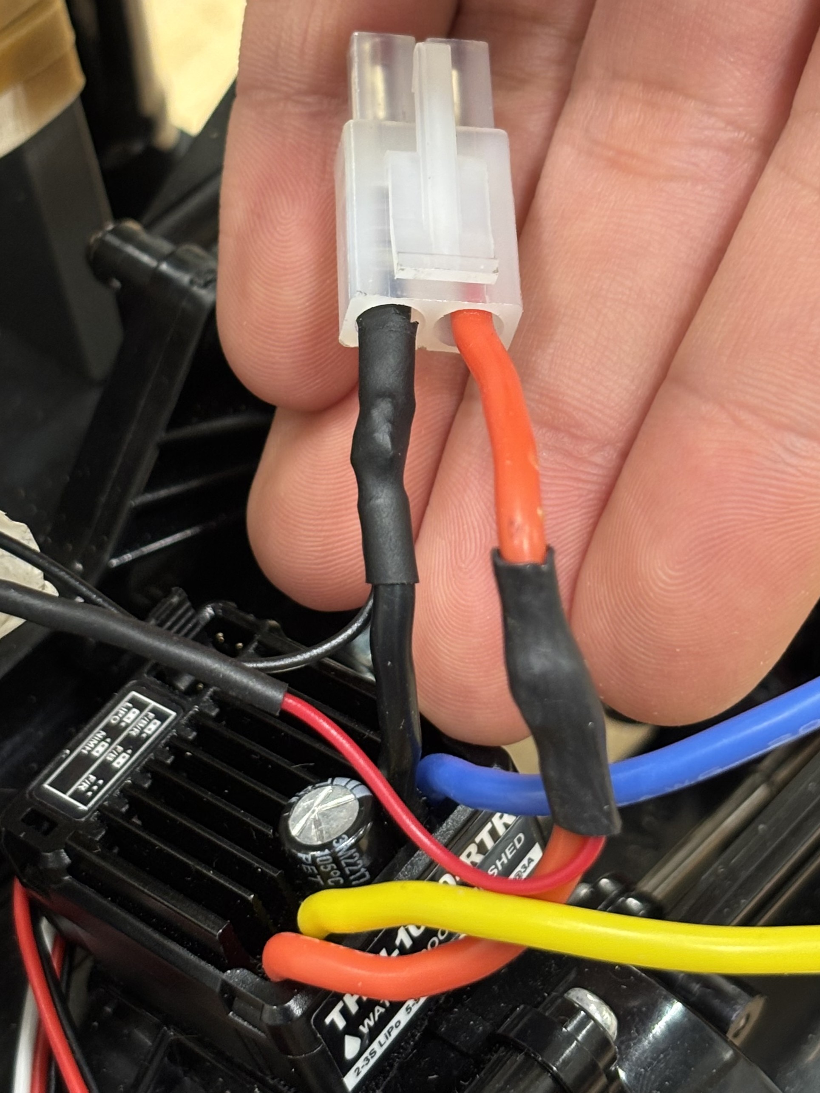
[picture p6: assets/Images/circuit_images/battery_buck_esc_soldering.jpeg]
Battery power split
  
</p>

- **Motor Driver / ESC**:  
  Connect the battery to the ESC only after the hardware and software setup is complete.  
  Attach the red wire (+) from the battery to **BAT+** on the ESC, and the black wire (–) to **BAT–**.

- **Motor Wiring**:  
  - Connect the **yellow wire** from the ESC (M3) to the **+ terminal** of the motor (yellow).  
  - Connect the **blue wire** from the ESC (M1) to the **– terminal** of the motor (green).  

- **Buck Converter (5V Power Split):**  
  Connect the buck converter to the battery (as described above).  
  Create a single 5V harness by soldering all red 5V leads together from **OUT +**, and a ground harness by soldering all black leads together from **OUT –**.  

  From this split:
  - **5V power (red):** one male connector (main feed), plus branches to both ESP32 boards (two female connectors), the ultrasonic sensor (male), the lidar (male), and the servo (male).  
  - **Ground (black):** common ground returning to **OUT –** for all the same devices. The ground from the buck converter is taken from **OUT –** via a male connector, then soldered to multiple cables that connect to the GND pins of different components:  
    - Servo (male)  
    - ESP32 board 1 (female)  
    - ESP32 board 2 (female)  
    - ESC (GND)  
    - Lidar (male)  
    - IMU (male)  
    - Encoder (male)  

- **ESP32 board (ESP1)**: Connect V5 and GND to the Buck converter as describes above.
- **ESP32 board (ESP2)**: Connect V5 and GND to the Buck converter as describes above.
- **Ultrasonic sensor**:  Connect V5 to the Buck converter as describes above. GND  connected to ground of ESP2 as digram, more soldering and modifications related to Data connection to be viewed later on. 
- **Lidar**: Connect V5 and GND to the Buck converter as describes above.

Both the encoder and the IMU are powered by the **3V3 pin of ESP2**, using two cables soldered together on the same 3V3 pin to provide a shared supply.

- **Encoder**:  
  - Use 3‑pin and 4‑pin screw terminal blocks soldered to the encoder.  
  - Power the encoder through its **VCC** pin using a cable screwed into the terminal block and connected to the **3V3 pin of ESP2** via a female connector (see [diagram](/assets/circuit/slamaleykoum_electrical_circuit.drawio.png)).  
  - Ground (GND) is connected to the buck converter’s ground harness as described above.

<p align="center">
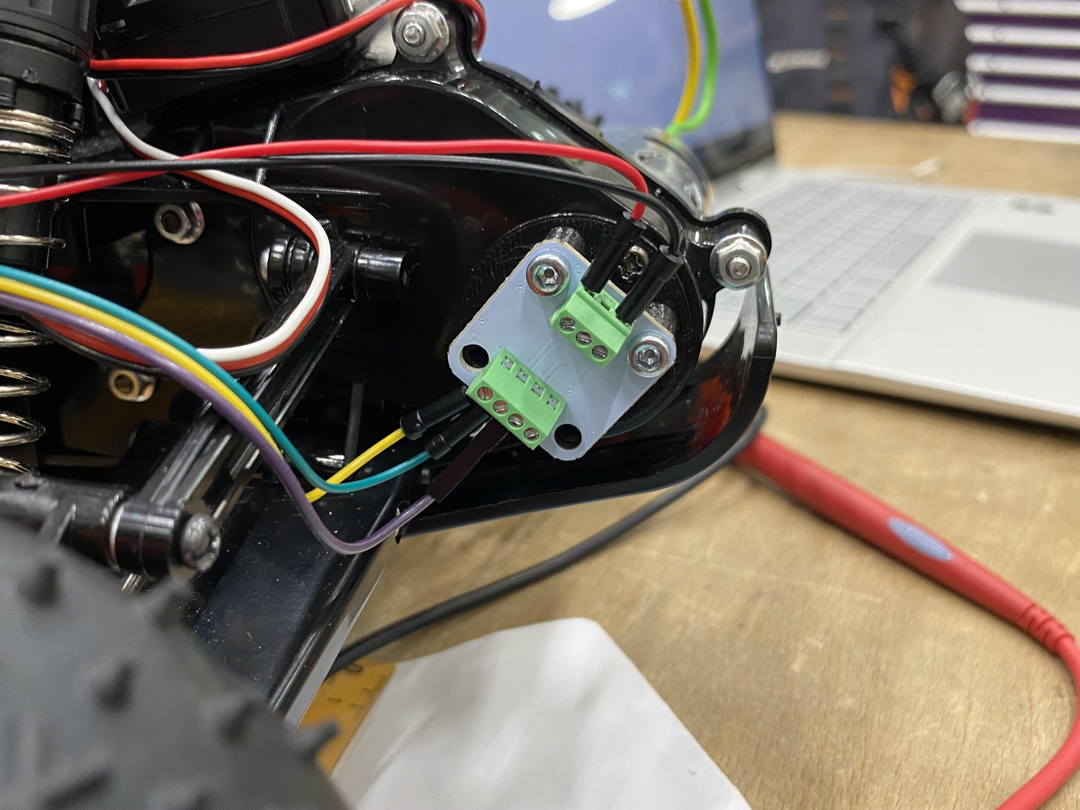
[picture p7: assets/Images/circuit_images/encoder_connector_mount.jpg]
Encoder screw terminal blocks
  
</p>

- **IMU**:  
  - Powered from the **3V3 pin of ESP2**, using a male connector on the IMU side and a female connector to ESP2 (see [diagram](/assets/circuit/slamaleykoum_electrical_circuit.drawio.png)).  
  - Ground (GND) is connected via a male connector on the IMU and a female connector on ESP2, both tied into the buck converter’s ground harness as described above.

#### Data Connections

- **Both ESPs**  
  - Communication via UART: connect pin 12 of ESP1 to pin 13 of ESP2, and pin 13 of ESP1 to pin 12 of ESP2 (light pink and blue cables on the [diagram](/assets/circuit/slamaleykoum_electrical_circuit.drawio.png)).

<p align="center">
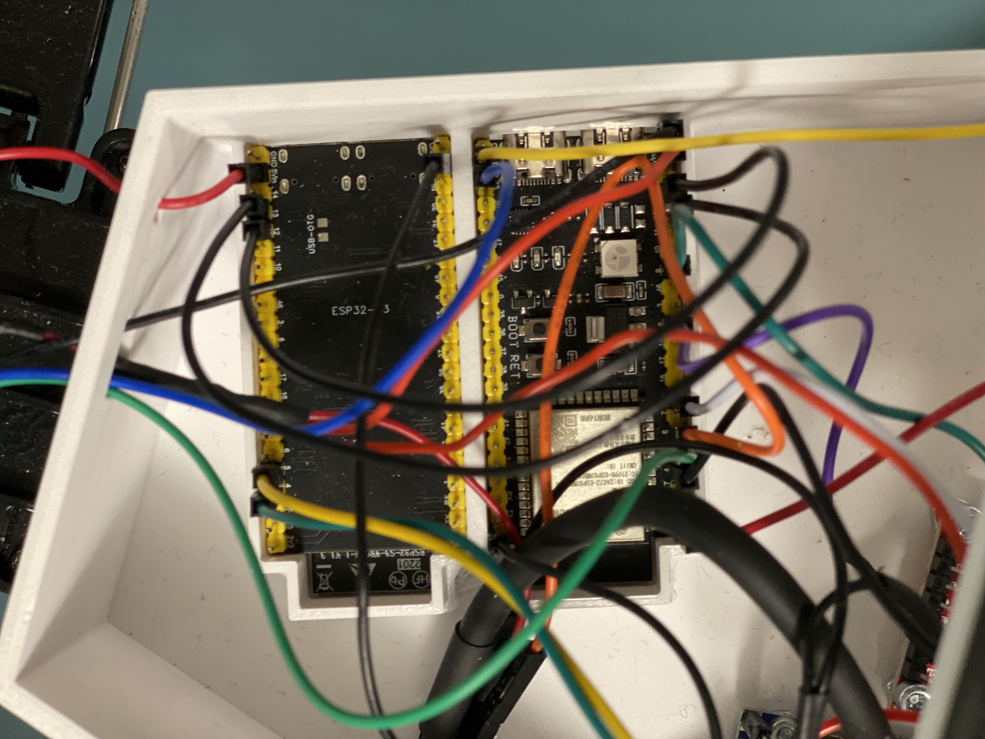
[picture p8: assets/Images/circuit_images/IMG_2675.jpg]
Both ESPs with their respective cables
  
</p>

- **ESP1**  
  - **Lidar**  
    - **TX**: male‑to‑female cable connected to pin 4 on ESP2 (green cable on [diagram](/assets/circuit/slamaleykoum_electrical_circuit.drawio.png)).  
    - **RX**: male‑to‑female cable connected to pin 5 on ESP2 (yellow cable on [diagram](/assets/circuit/slamaleykoum_electrical_circuit.drawio.png)).

- **ESP2**  
  - **Motor Driver**  
    - **PWM**: male‑to‑female cable connected to pin 15 on ESP2 (grey cable on [diagram](/assets/circuit/slamaleykoum_electrical_circuit.drawio.png)).  

  - **Servo**  
    - **Pulse**: male‑to‑female cable connected to pin 6 on ESP2 (orange cable on [diagram](/assets/circuit/slamaleykoum_electrical_circuit.drawio.png)).  

  - **Encoder**  
    - **DIR**: male‑to‑female cable connected to GND on ESP2 (yellow cable on [diagram](/assets/circuit/slamaleykoum_electrical_circuit.drawio.png)).  

  - **IMU**  
    - **INT**: male‑to‑female cable connected to pin 4 on ESP2 (black cable on [diagram](/assets/circuit/slamaleykoum_electrical_circuit.drawio.png)).  

  - **I²C Bus (shared between Encoder & IMU)**  
    - **SDA**: two male cables (encoder + IMU) soldered together into a female connector, attached to pin 8 on ESP2 (purple cable on [diagram](/assets/circuit/slamaleykoum_electrical_circuit.drawio.png)).  
    - **SCL**: two male cables (encoder + IMU) soldered together into a female connector, attached to pin 9 on ESP2 (green cable on [diagram](/assets/circuit/slamaleykoum_electrical_circuit.drawio.png)).
  - **Ultrasonic Sensor (HC‑SR04) — Voltage Divider on Echo Pin**  
    - The HC‑SR04 must be powered at **5V** (from the buck converter).  
    - Its **ECHO pin outputs 5V**, which is too high for the ESP32’s 3.3V GPIO.  
    - To reduce this safely, we use a **resistor voltage divider**.

    - ***Circuit Description:***  
      - **Resistors used**: three resistors, each 1 kΩ.  
      - **Ground reference**: a black cable from the sensor’s GND is soldered to two resistors in series.  
      - **Divider branch**: these two resistors connect to a blue cable, which then passes through a third 1 kΩ resistor.  
      - **Echo connection**: the third resistor is connected to the sensor’s **ECHO pin** (via male connector).  
      - **ESP32 input**: the other end of the blue cable is connected to **ESP2 pin 19** (via female connector).  
      - **Result**: the divider steps the 5V ECHO signal down to ~3.3V, safe for the ESP32.

    - ***Summary:***  
      - **Trig**: male‑to‑female cable connected directly to **ESP2 pin 5** (green cable on [diagram](/assets/circuit/slamaleykoum_electrical_circuit.drawio.png)).  
      - **Echo**: routed through the resistor voltage divider before reaching **ESP2 pin 19** (female connector).
<p align="center">
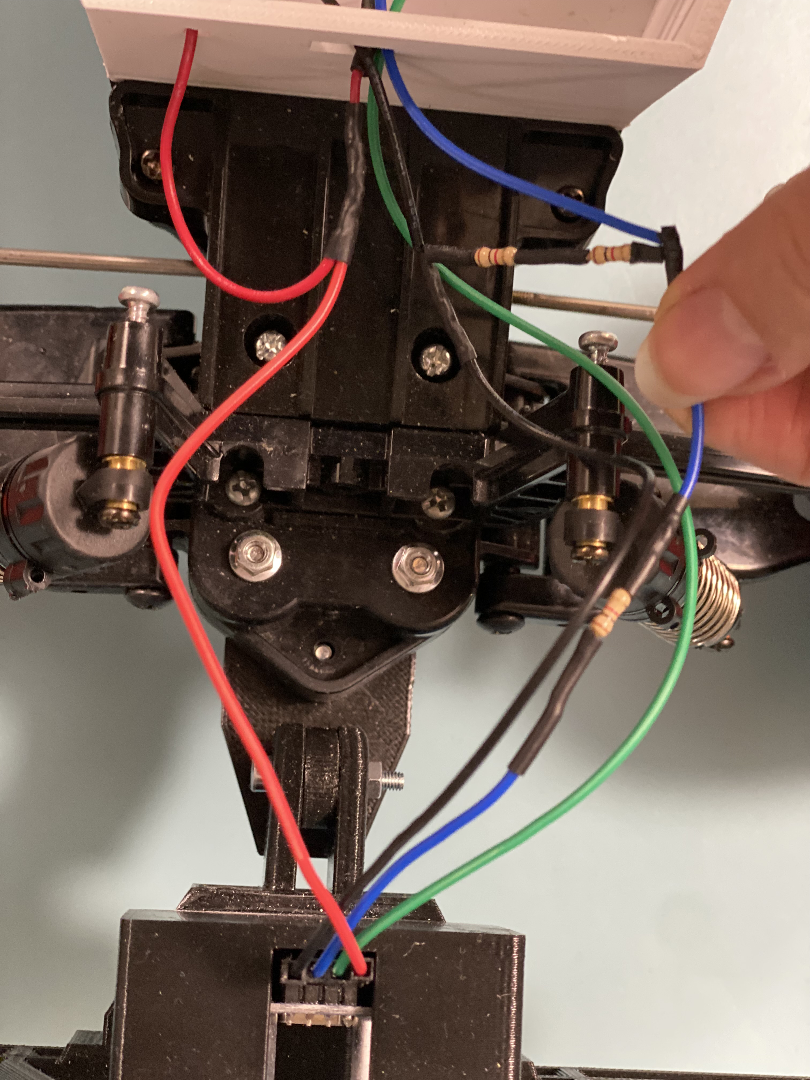
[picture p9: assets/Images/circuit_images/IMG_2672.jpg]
Ultra sonic cables
  
</p>

If you want to view more pictures of the car check : [Here](/assets/Images/Photoshoot/)

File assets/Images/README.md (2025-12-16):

# Our SLAM Car

## Before

<div align="center">

| Left Side | Top | Right Side |
|---|---|---|
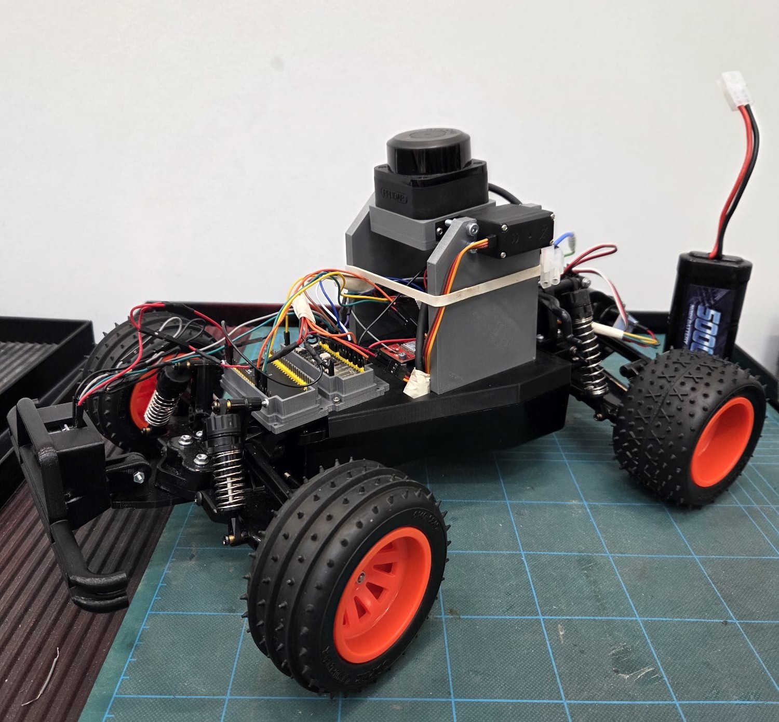
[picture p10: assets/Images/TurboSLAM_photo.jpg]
Side
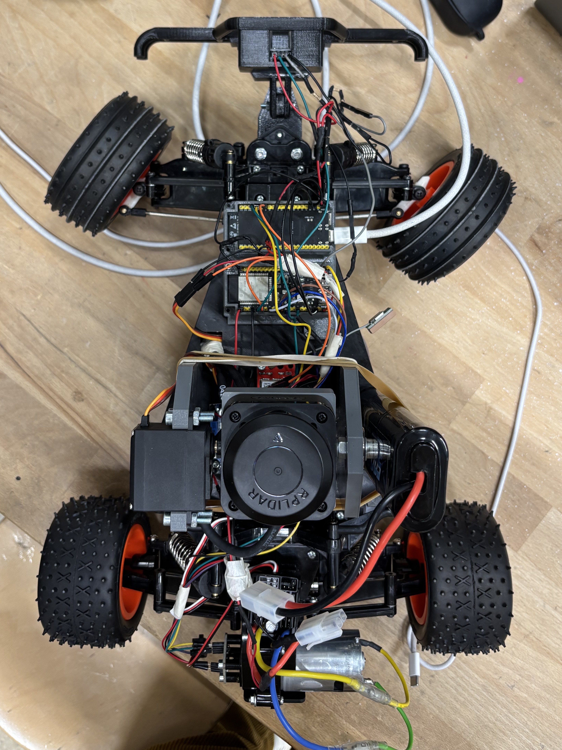
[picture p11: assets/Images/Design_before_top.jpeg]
Top design before
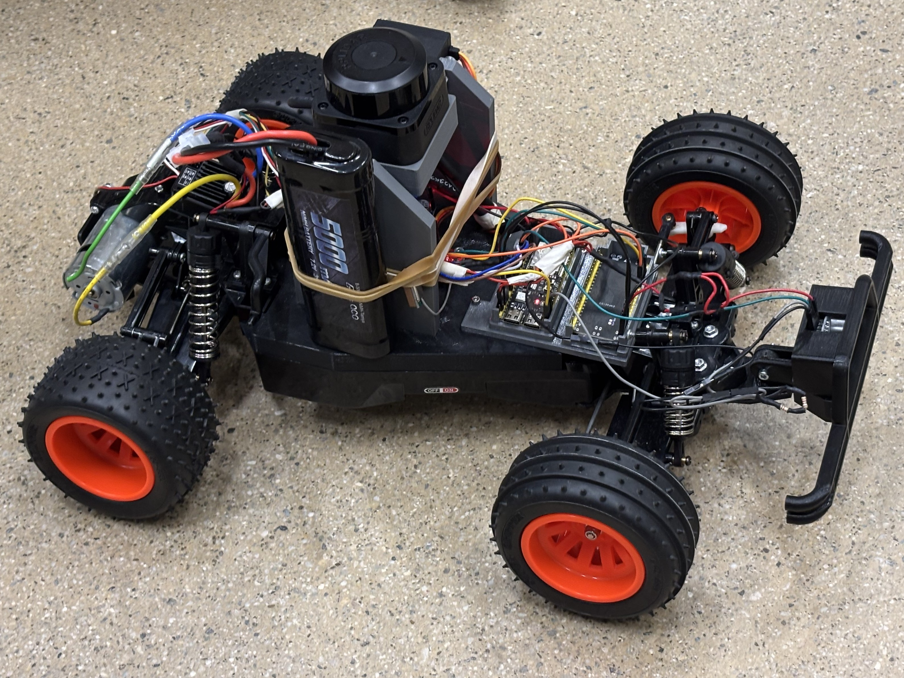
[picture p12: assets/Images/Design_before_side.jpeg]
Side design before
|  |   |  |

</div>

## During

<p align="center">
  <b>Wiring</b><br>
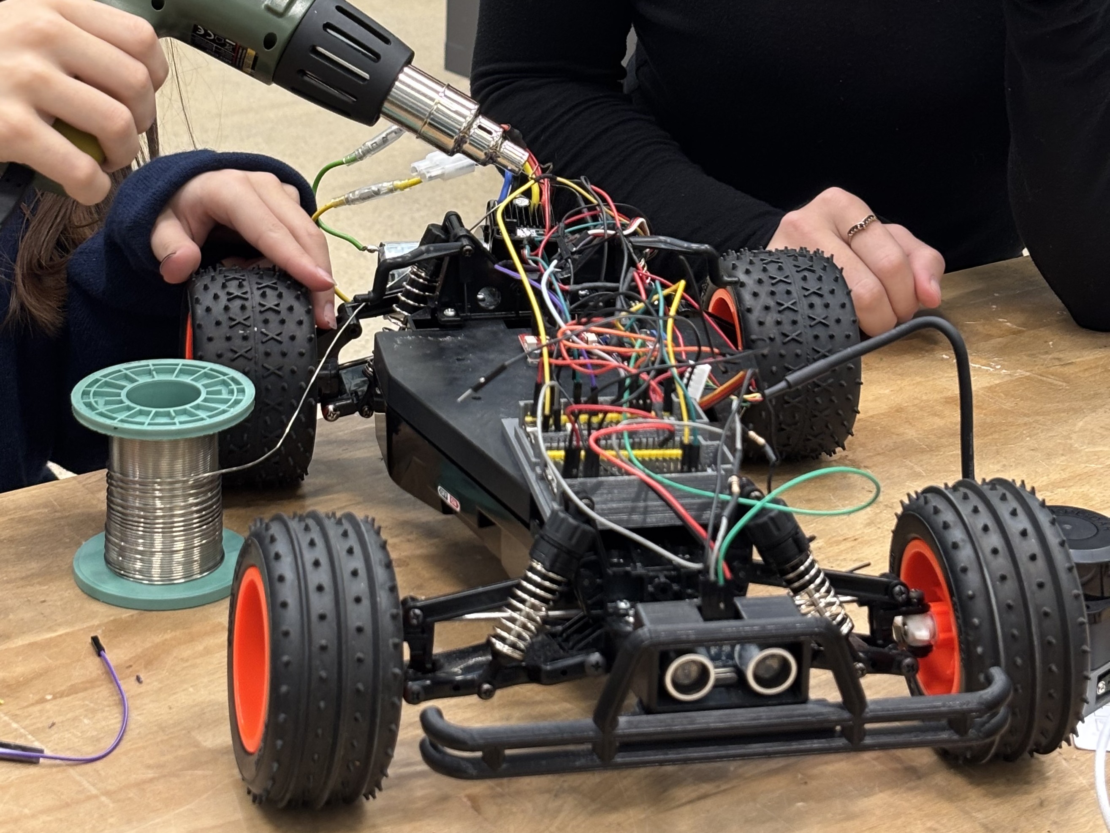
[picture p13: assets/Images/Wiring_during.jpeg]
Wiring
  
</p>

<p align="center">
  <b>3D printing</b><br>
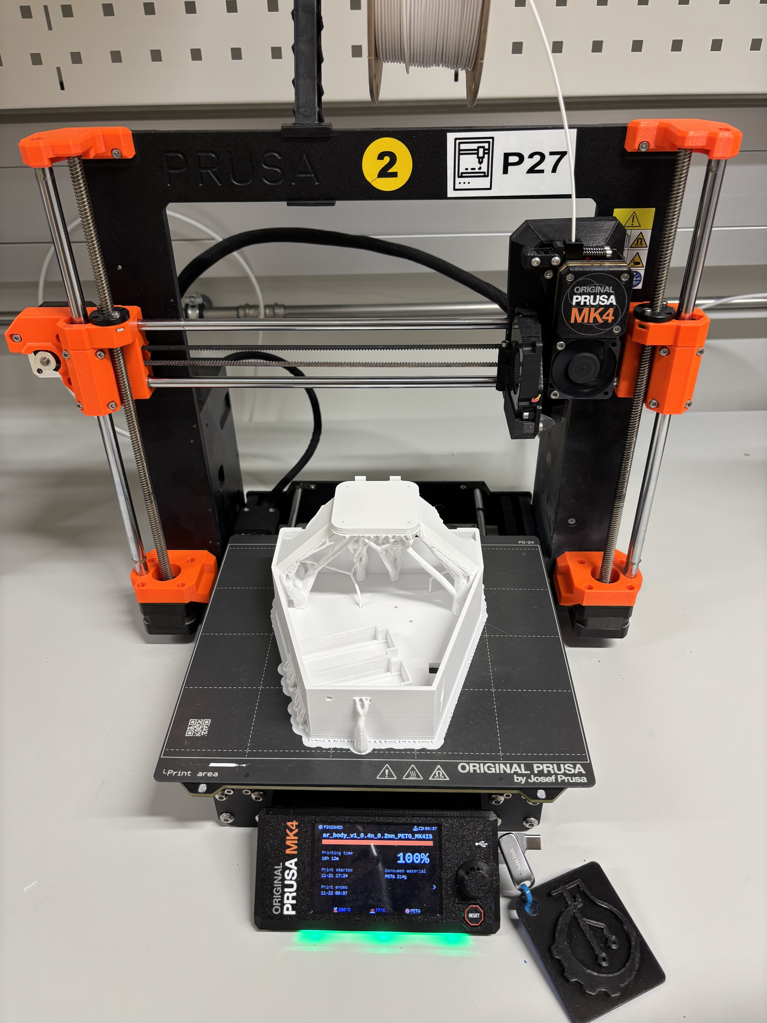
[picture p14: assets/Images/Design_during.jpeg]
3D printing
  
</p>

## After

<div align="center">

| Left side | Top | Right Side |
|---|---|---|
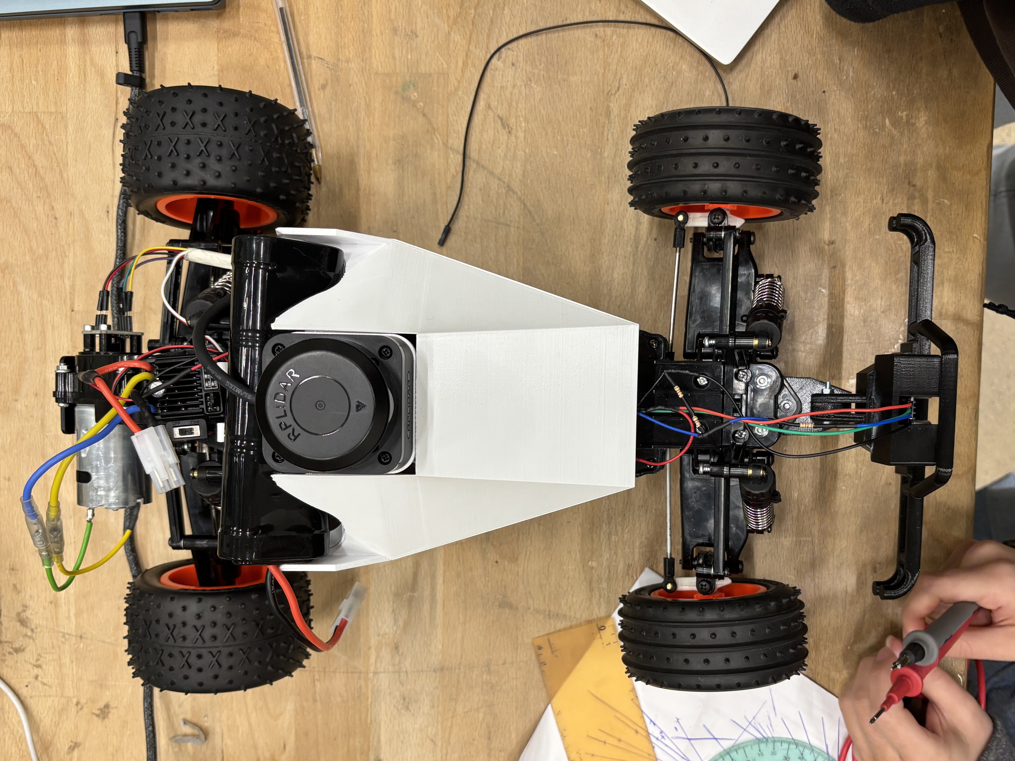
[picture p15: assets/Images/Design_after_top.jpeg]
Top after
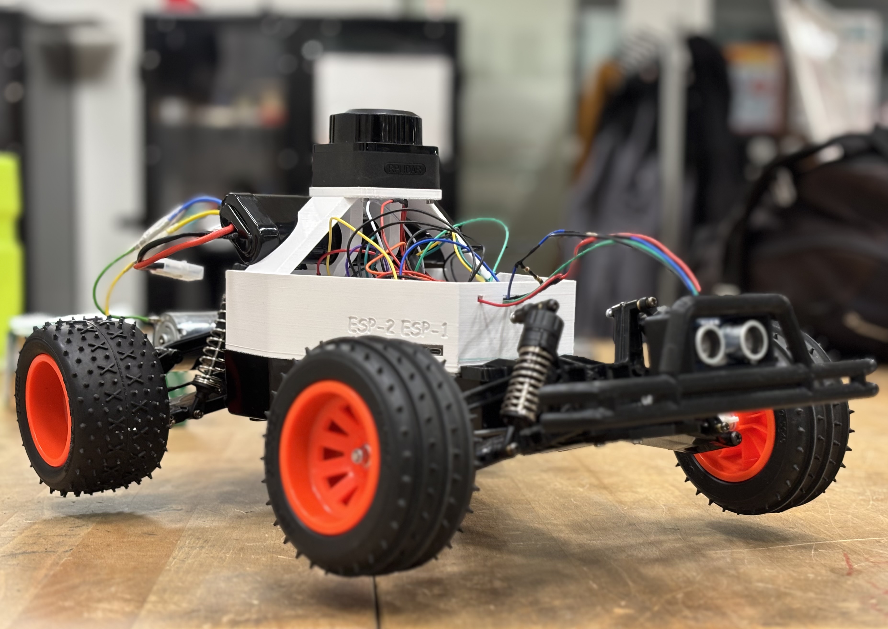
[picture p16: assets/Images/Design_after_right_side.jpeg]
Right side
| Left side |  |  |

</div>

If you want to view more pictures of the car check : [Here](/assets/Images/Photoshoot/)

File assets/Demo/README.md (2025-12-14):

# Demo

## The SLAM car's look

Here is a video showing the car's design: 
(TODO : insert video)

## The car in action (localizing and mapping)

### View in real life :
(TODO : insert video)
### View from the map : 
(TODO : insert screenshot and/or video of map getting updated)

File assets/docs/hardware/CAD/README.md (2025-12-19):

## 3D Printed Parts (CAD Files)

This folder contains the STL files for all custom 3D‑printed parts used in the car build.  
Each part has its STL file and a reference photo of the real‑life assembly.

### Front Bumper & Ultrasonic Sensor Case
Mounted at the front of the car to hold and protect the ultrasonic sensor.
- [bumper_and_carattach.stl](\assets\CAD\bumper_and_carattach.stl)  
- [ultrasonicsensor_case.stl](\assets\CAD\ultrasonicsensor_case.stl)  

<p align="center">
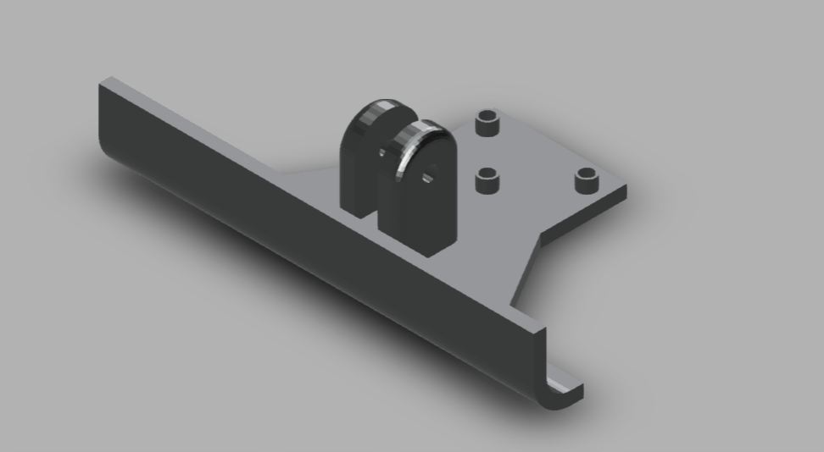
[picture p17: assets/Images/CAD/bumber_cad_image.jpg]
Bumper
  
</p>
<p align="center">
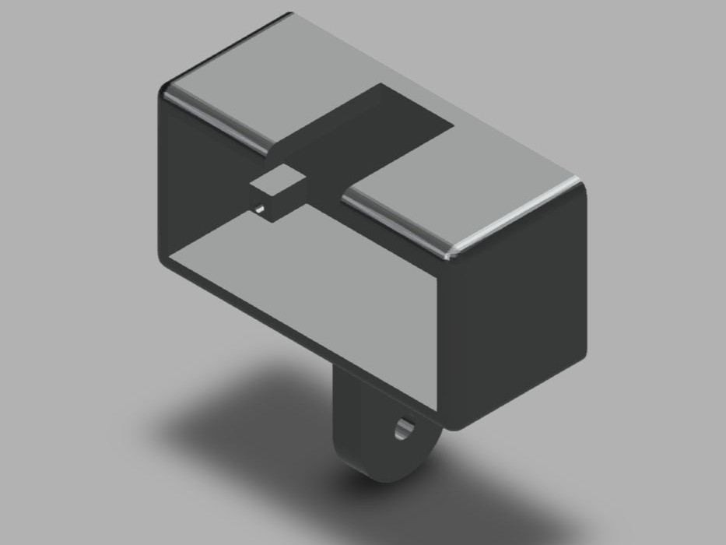
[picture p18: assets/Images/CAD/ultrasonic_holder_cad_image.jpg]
Ultrasonic Sensor Holder
  
</p>
<p align="center">
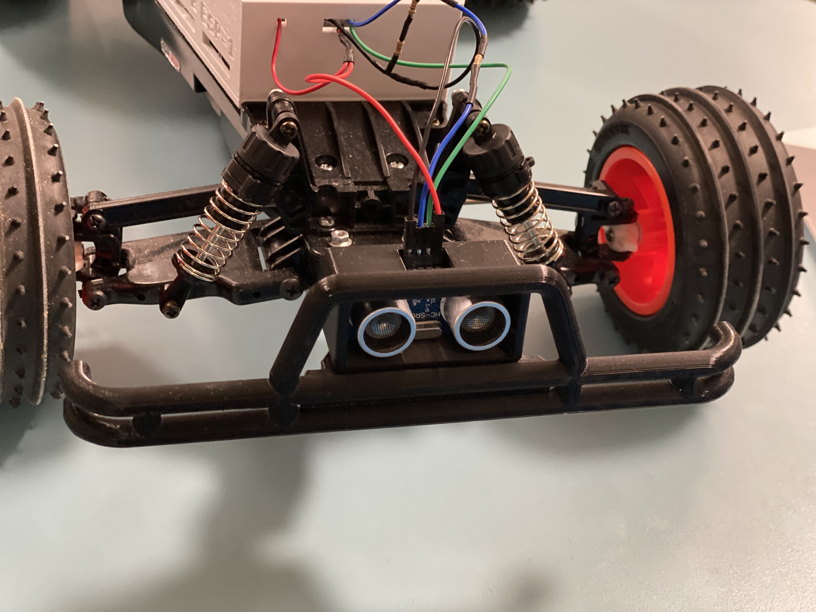
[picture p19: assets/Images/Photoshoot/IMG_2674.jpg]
Both in real-life photo
  
</p>

### Encoder Mount
Placed in front of the motor to secure the encoder and its magnet.
- [encoder_support.stl](\assets\CAD\encoder_support.stl)  

<p align="center">
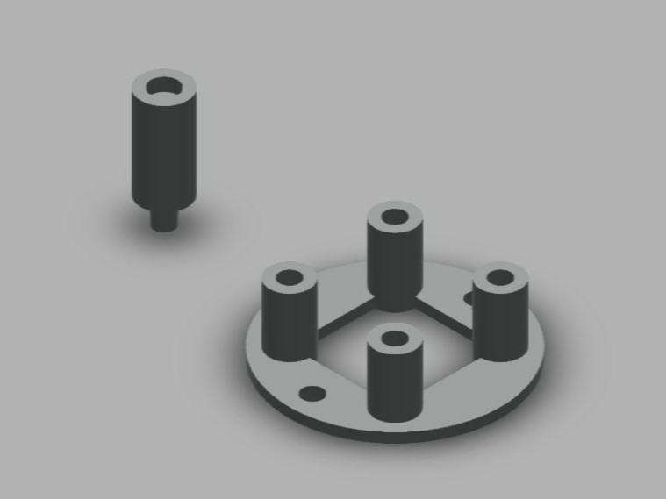
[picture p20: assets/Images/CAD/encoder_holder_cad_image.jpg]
Encoder Mount
  
</p>

### Car Body Platform
Main body layer where most hardware components (ESP boards, lidar, buck converter, IMU, etc.) are mounted.
- [MIT_car_body.stl](\assets\CAD\MIT_car_body.stl)  

<p align="center">
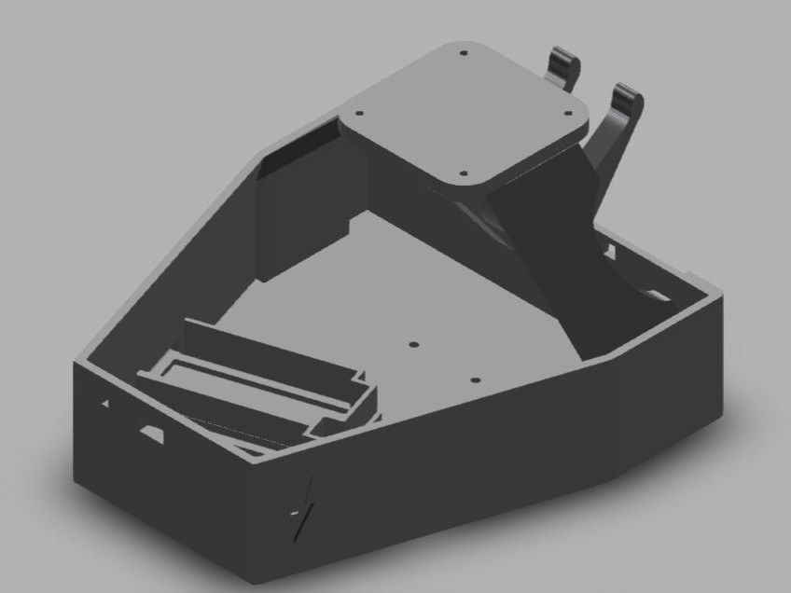
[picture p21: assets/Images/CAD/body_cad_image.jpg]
Car Body
  
</p>

### Roof Cover
Top cover that hides components and cables for a cleaner look.  
It also secures the battery in place.
- [MIT_roofstl](\assets\CAD\MIT_roofstl)  

<p align="center">
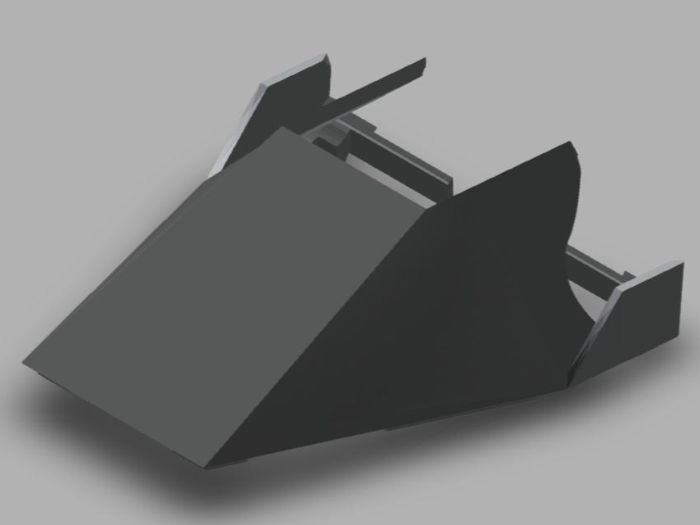
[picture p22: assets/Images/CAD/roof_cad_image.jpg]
Roof
  
</p>

### Body & Roof Cover

<p align="center">
  <video width="500" controls>
    <source src="/assets/CAD/body_roof_video.mp4" type="video/mp4">
    Your browser does not support the video tag.
  </video>
</p>

Note: The CAD files for the **front bumper**, **ultrasonic sensor case**, and **encoder mount** were originally designed by the group from whom we inherited the car, **TurboSLAM**.

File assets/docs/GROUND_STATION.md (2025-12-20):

🏠 [Backlink to the main README](/README.md)

# Ground Station - Real-Time SLAM Visualization

## Overview

Live telemetry dashboard. Displays real-time mapping, navigation, and CPU profiling data over WiFi.

**Features:**
- Live occupancy grid map
- Robot pose and navigation path visualization
- Real-time task execution timeline (CPU profiling)
- Performance metrics and system health monitoring
- Automatic telemetry logging
- Frontier detection overlay (Not currently working)

## Quick Start

### Connect & Run

1. **Connect to car WiFi:**
   ```
   SSID: LIDAR_AP
   Password: l1darpass
   ```

2. **Launch ground station:**
   ```bash
   python ground_station.py
   ```

NOTE: It is normal that the car starts mooving before you've got time to connect. If you can't connect, checkout [the trouble shooting page](/assets/docs/troubleshooting.md).

## Display Layout

```
┌─────────────────────────────────────────────────┐
│  HUD (Top-Left)          MAP WINDOW             │
│  - Robot Position        - Black: Walls         │
│  - Goal Position         - White: Free Space    │
│  - System State          - Grey: Unknown        │
│  - Performance Stats     - Red Dot: Robot       │
│  - Memory Usage          - Green Circle: Goal   │
│                          - Yellow dots: Path    │
│                          - Blue Trail: History  │
│                                                 │
│ (Cyan frontiers, are not working at the moment) │
├─────────────────────────────────────────────────┤
│  TIMELINE (CPU Profiling)                       │
│  ┌─ Core 0 ──────────────────────────────────┐  │
│  │ [IPC] [GPLAN] [MPLAN] [TCP]               │  │
│  └───────────────────────────────────────────┘  │
│  ┌─ Core 1 ──────────────────────────────────┐  │
│  │ [LIDAR] [SYNC] [MAP]                      │  │
│  └───────────────────────────────────────────┘  │
├─────────────────────────────────────────────────┤
│  LEGEND: Task Colors                            │
│  ■ LIDAR  ■ SYNC  ■ MAP  ■ IPC  ■ GPLAN ...     │
└─────────────────────────────────────────────────┘
```

## What You'll See

### Map Visualization
- **Occupancy Grid**: Bayesian map showing explored areas
- **Robot (Red Dot)**: Current position with heading arrow
- **Goal (Green Circle)**: Mission planner target with heading
- **Path (Yellow Dots)**: A* global path from robot to goal
- **Frontiers (Cyan Dots)**: Unexplored boundary cells for autonomous exploration
- **Trail (Blue)**: Historical path showing where robot has been

### Timeline Panel
Real-time CPU profiling showing task execution on both cores:
- **Horizontal bars**: Task execution periods
- **Bar width**: Execution duration
- **Bar color**: Task type (see legend)
- **Two lanes**: Core 0 (top) and Core 1 (bottom)
- **Scrolling window**: Shows last 1 second of activity

Note: More information about the profiling can be found [here](assets/docs/debugging/CPU_PROFILING.md)

### HUD Information

```
POS   : X 2.45 Y 1.23        ← Robot position (meters)
GOAL  : X 3.50 Y 2.10        ← Current navigation goal
STATE : EXPLORATION          ← Mission state
--- PERF (us) ---
MAP UPDATE : 1834            ← Bayesian grid update time
GLOB PLAN  : 4678            ← A* pathfinding time
MISS PLAN  : 1245            ← Mission planning time
--- CORE 1 DIAG ---
LIDAR RX  : 14               ← Total LiDAR scans received
MAP UPDT  : 18               ← Successful map updates
SYNC DROP : 4                ← Dropped sync frames
MTX FAIL  : 2                ← Mutex acquisition failures
--- MEM (KB) ---
FREE HEAP : 856.2 KB         ← Available RAM
MIN HEAP  : 842.8 KB         ← Minimum free RAM seen
--- STACKS ---
TCP:1234 GP:2345 MP:3456 LI:4567  ← Stack watermarks
ESP2:45ms PKT:5678            ← ESP2 connection & packet count
TRACE: 1847 events            ← Profiling events in packet
```

## Data Logging

All telemetry is automatically logged to CSV:

**Filename Format:** `telemetry_trace_YYYYMMDD_HHMMSS.csv`

**Columns:**
```csv
Timestamp_PC,ESP_Time_us,Task_ID,Core,Event_Type
1702350445.123,1234567,3,1,1
1702350445.135,1246789,3,1,0
```

- `Timestamp_PC`: Python timestamp when packet received
- `ESP_Time_us`: ESP32 microsecond timestamp
- `Task_ID`: 1-8 (see task mapping below)
- `Core`: 0 or 1
- `Event_Type`: 1=START, 0=END

Use this CSV with `plot_trace.py` for offline analysis.

## Task ID Mapping

| ID | Name | Core | Function |
|----|---|---|---|
| 1 | LIDAR | 1 | LiDAR data acquisition |
| 2 | SYNC | 1 | Pose-scan fusion |
| 3 | MAP | 1 | Bayesian grid updates |
| 4 | IPC | 0 | Inter-ESP communication |
| 5 | GPLAN | 0 | Global path planning |
| 6 | MPLAN | 0 | Mission planning |
| 7 | TCP | 0 | Telemetry transmission |
| 8 | VALID | 0 | Pose validation |

## Configuration

Edit constants at the top of `ground_station.py`:

```python
# Network
ESP_IP = "192.168.4.1"
PORT = 9000

# Map (MAKE SURE THEY MATCH WITH main_esp1.cpp and data_typed.h)
GRID_W = 70           # Grid width (cells)
GRID_H = 70           # Grid height (cells)
RESOLUTION = 0.15     # Cell size (meters)
WINDOW_SCALE = 13     # Display scale factor

# Timeline
max_history_us = 1000000  # Show last 1 second (line 169)
```

## How It Works

### 1. TCP Protocol

The ESP32 sends binary packets every 100ms containing:

```
┌─────────────┬──────────┬──────────┬─────────┬─────────┐
│ Header (96B)│ Trace(2B)│ Path(var)│ Map(var)│ Events  │
│             │  Count   │          │  (RLE)  │ (var)   │
└─────────────┴──────────┴──────────┴─────────┴─────────┘
```

**Header Contains:**
- Magic bytes (0xBEEF)
- Map size (uint32)
- Path length (uint16)
- Robot pose (3x float)
- Goal pose (3x float)
- System state (uint8)
- System health (64 bytes)

### 2. Map Decompression

Maps are transmitted using Run-Length Encoding (RLE):

```python
def rle_decode(rle_data, total_size):
    # Input: [Count, Value, Count, Value, ...]
    # Output: Decompressed int8 array (log-odds)
    decoded = np.zeros(total_size, dtype=np.int8)
    for count, value in pairs(rle_data):
        decoded[idx:idx+count] = value
        idx += count
    return decoded
```

Converts log-odds to RGB:
- `> 4`: Occupied → Black
- `< -6`: Free → White
- Otherwise: Unknown → Grey

### 3. Timeline Rendering

```python
class Timeline:
    def add_events(self, events):
        # Match START/END pairs
        for ts, task_id, event_type, core in events:
            if event_type == START:
                active_tasks[task_id] = ts
            elif event_type == END:
                start = active_tasks.pop(task_id)
                duration = ts - start
                history.append({
                    'start': start,
                    'end': ts,
                    'core': core,
                    'id': task_id
                })
```

Draws horizontal bars for each completed task execution.

### 4. Coordinate Transforms

**World → Screen:**
```python
def world_to_screen(wx, wy):
    # Convert meters to pixels
    pixels_per_meter = (1.0 / RESOLUTION) * WINDOW_SCALE
    sx = center_x + (wx * pixels_per_meter)
    sy = center_y - (wy * pixels_per_meter)  # Invert Y
    return int(sx), int(sy)
```

**World → Grid:**
```python
def world_to_index(wx, wy):
    # Convert meters to grid indices
    ix = int(wx / RESOLUTION) + (GRID_W // 2)
    iy = (GRID_H // 2) - int(wy / RESOLUTION)
    return ix, iy
```

## Troubleshooting

### Connection Issues

**Can't connect to robot:**
```
Error: [Errno 111] Connection refused
```
- Check WiFi connection to `LIDAR_AP`
- Verify esp1 is powered on
- Verify you uploaded the correct code _(sadly happens way to often)_

## Keyboard Controls

- **c**: Clear car trace
- **ctrl + w**: close window $\rightarrow$ Save CSV and exit

## Output Files

When you close the ground station:
```
Session complete. Log saved to: telemetry_trace_20241220_153045.csv
```

Use this file with:
```bash
python plot_trace.py telemetry_trace_20241220_153045.csv
```

## Integration with Profiling System

The ground station is part of the complete profiling workflow:

1. **ESP32** → Logs task events with `log_event()`
2. **TCP Task** → Transmits events every 100ms
3. **Ground Station** → Displays live timeline + saves CSV
4. **plot_trace.py** → Generates detailed Gantt charts from CSV

See [`CPU_PROFILING_README.md`](/assets/docs/debugging/CPU_PROFILING.md) for the complete system documentation.

---

**Last Updated**: December 2025

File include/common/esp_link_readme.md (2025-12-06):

# ESP-to-ESP High-Speed UART Link  
**Binary communication protocol between two ESP32-S3 boards**

This module implements a fast, compact and deterministic communication layer between two ESP32-S3 boards using a dedicated **2 Mbaud UART link**.  
It transmits structured data (poses, paths…) as raw binary without serialization overhead.

---

## Hardware setup

Two ESP32-S3 DevKitC boards wired as:

| ESP1 pin | ESP2 pin |
|---|---|
| TX (GPIO 12) → | RX (GPIO 13) |
| RX (GPIO 13) ← | TX (GPIO 12) |

Notes:
- **GND must be shared**
- Boards may be powered independently (USB/battery)

---

## Features

- **Binary protocol** with minimal overhead  
- **Header-based message identification**  
- **Raw struct transmission** (no JSON, no strings)  
- **High throughput**: 2'000'000 baud  
- **Zero-copy send** using reinterpret_cast  
- **FIFO queue** for Pose2D  
- **Last-value store** for GlobalPathMessage  

---

## Message Types

### Pose2D (`MSG_POSE`)

```cpp
struct Pose2D {
    float x;
    float y;
    float theta;
    uint32_t timestamp_ms;
};
```

Handled with:
- `sendPos()`
- `get_pos()`

Stored in a FIFO queue (capacity 4).

---

### GlobalPathMessage (`MSG_PATH`)

```cpp
struct Waypoint { float x; float y; };

struct GlobalPathMessage {
    Waypoint path[MAX_PATH_LENGTH];
    uint16_t current_length;
    uint32_t path_id;
    uint32_t timestamp_ms;
};
```

Handled with:
- `sendPath()`
- `get_path()`

Only the **most recently received** path is stored.

---

## Protocol Description

Each message begins with a **1-byte header**:

```
bits: [MSG_ID (3 bits)] [unused (5 bits)]
```

Payload follows immediately in raw memory format.

No checksum or framing → assumes clean UART.

---

## API Overview

```cpp
Esp_link link(Serial1);

link.begin();         // initialize UART
link.poll();          // process incoming messages

link.sendPos(p);      // send Pose2D
link.sendPath(gpm);   // send GlobalPathMessage

Pose2D p;
if (link.get_pos(p)) {
    // consume pose
}

GlobalPathMessage path;
link.get_path(path);  // always returns the latest path
```

---

## Internal Behavior

### Pose2D queue
- Circular buffer (capacity 4)
- Overflows drop the oldest entry
- Non-blocking polling

### GlobalPathMessage
- Only the most recent message is kept

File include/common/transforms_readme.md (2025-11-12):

# **Transforms Library (transforms.h)**

## **Overview**

This is a lightweight, header-only utility library for performing 2D coordinate transformations. It is designed to convert points between the **global** coordinate frame and the **robot-centric** coordinate frame.  
**The functions in this library are inline for performance and modify the Waypoint object in-place.**

## **1\. Coordinate System Definition**

This library assumes a specific coordinate system for the robot based on our IMU orientation on the physical car.

* **Robot Frame:**  
  * **Y-axis:** Points **forward**.  
  * **X-axis:** Points to the **right**.  
  * **Origin:** Center of the car's rear axle.
* **Global Frame:**  
  * The X and Y axes are defined by the robot's orientation at startup (assumed known axis).  
* **Angle (Pose2D::theta):**  
  * Represents the robot's heading.  
  * It is the counter-clockwise (CCW) angle from the **Global X-axis** to the **Robot's X-axis**.  
  * A theta of 0 means the robot's X-axis is aligned with the Global X-axis (and Y-axis with Y-axis).  
  * A theta of 90 degrees (M\_PI / 2.0) means the robot is facing along the Global Y-axis.

## **2\. API Functions**

### **void Transforms::to\_robot\_frame(const Pose2D& robot\_pose, Waypoint& point)**

* **Purpose:** Converts a Waypoint from global coordinates to robot-centric coordinates.  
* **Inputs:**  
  * robot\_pose: The current Pose2D (x, y, theta) of the robot in the global frame.  
  * point: The Waypoint (x, y) in global coordinates.  
* **Output:** The point object is modified **in-place** to contain its (x, y) coordinates relative to the robot.

### **void Transforms::to\_global\_frame(const Pose2D& robot\_pose, Waypoint& point)**

* **Purpose:** Converts a Waypoint from robot-centric coordinates back to global coordinates.  
* **Inputs:**  
  * robot\_pose: The current Pose2D (x, y, theta) of the robot in the global frame.  
  * point: The Waypoint (x, y) in robot-centric coordinates.  
* **Output:** The point object is modified **in-place** to contain its (x, y) coordinates in the global frame.

## **3\. Usage Example**

This example shows how to take a global point, convert it to the robot's frame, and then convert it back to global.
```
#include "common/data_types.h"  
#include "common/transforms.h"  
#include <iostream>  
#include <cmath> // For M_PI

int main() {  
    // 1. Define the Robot's Pose  
    // Robot is at (x=10, y=5) in the global frame.  
    // It is rotated 90 degrees CCW (theta = PI/2).  
    // This means the robot's Y-axis (front) points along the global Y-axis.  
    Pose2D robot_pose = {10.0f, 5.0f, M_PI / 2.0f};

    // 2. Define a Global Point  
    // A point 3 meters in front of the robot.  
    Waypoint global_point = {10.0f, 8.0f};

    std::cout << "Original Global Point: ("   
              << global_point.x << ", " << global_point.y << ")" << std::endl;

    // 3. Convert to Robot Frame  
    Waypoint robot_point = global_point; // Make a copy  
    Transforms::to_robot_frame(robot_pose, robot_point);

    // With X-Right, Y-Fwd frame:  
    // The point is 0m to the right (x=0) and 3m in front (y=3).  
    std::cout << "Robot-Frame Point:     ("   
              << robot_point.x << ", " << robot_point.y << ")" << std::endl;  
    // Expected Output: (0, 3) (or very close due to float precision)

    // 4. Convert Back to Global Frame  
    Transforms::to_global_frame(robot_pose, robot_point);

    std::cout << "Reverted Global Point: ("
              << robot_point.x << ", " << robot_point.y << ")" << std::endl;
    // Expected Output: (10, 8)  

    return 0;  
}
```

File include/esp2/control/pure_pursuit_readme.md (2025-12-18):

# Pure Pursuit – Local Path Tracker

## Overview

This module implements a **Pure Pursuit local path-following controller** designed to run on the ESP32.  
Its role is to convert a **short global path** (received from ESP1) into **low-level motion commands** that allow the vehicle to follow the path smoothly and reliably.

Due to hardware limitations of the ESC, the current implementation uses a **fixed target speed** and a **fixed lookahead distance**, focusing on robust steering computation rather than full dynamic control.

---

## Core Concept

The Pure Pursuit algorithm follows a path by continuously steering the vehicle toward a **lookahead point** located at a fixed distance ahead of the robot on the path.

The algorithm works as follows:

1. **Path Update**  
   A new path is frequently received from ESP1 and **completely overwrites** the previous one.  
   Since paths are always recomputed from the robot’s current position, no path continuity is required.

2. **Lookahead Point Selection**  
   - The algorithm searches forward along the path starting from the last valid index.
   - It computes the intersection between path segments and a **lookahead circle** centered on the robot.
   - If multiple intersections exist, the **furthest valid one** along the path is selected.
   - If no intersection is found, the closest point on the path is used as a fallback.

3. **Coordinate Transformation**  
   The selected lookahead point is transformed from the **global frame** to the **robot frame** using the `Transforms` utility.

4. **Steering Computation (Bicycle Model)**  
   The curvature is computed using the Pure Pursuit formula:
   $(\mathbf{curvature = 2 * x}_{\text{lateral}} \mathbf{/ Ld²})$
  where:
  - `x_lateral` is the lateral offset of the lookahead point in robot coordinates
  - `Ld` is the fixed lookahead distance    
  The steering angle is then computed as:   
  $(\mathbf{steering\_angle} \mathbf{= atan(curvature * L)})$      
  where `L` is the vehicle wheelbase.

5. **Command Output**  
- The steering angle is clamped to the physical limits of the vehicle.
- It is converted to **servo degrees** (`0–180`, with `90` as straight).
- A fixed forward speed is applied.

---

## Design Choices & Constraints

- **Fixed Speed and Lookahead**  
Adaptive speed and lookahead are disabled due to ESC limitations.

- **Forward Progress Enforcement**  
A sliding index ensures the robot always follows points ahead of its current position and never tracks backward along the path.

- **Continuous Path Refresh**  
The controller assumes paths are continuously updated and does not rely on explicit “path completed” events.

---

## Key Parameters

Defined in `pure_pursuit.h`:

- `L_` – Vehicle wheelbase (meters)
- `Ld_fixed_` – Fixed lookahead distance
- `fixed_speed_` – Fixed target speed
- `k_p` – Proportional gain applied to curvature
- `MIN_STEERING_ANGLE_RAD_ / MAX_STEERING_ANGLE_RAD_` – Steering limits
- `goal_tolerance_` – Distance threshold for goal detection
---

## Public API

### `void set_path(const PathMessage& path_msg)`

**Purpose**  
Loads a new path to follow.

**Behavior**
- Copies the received waypoints into an internal buffer
- Resets the lookahead index
- Overwrites any previously active path

---

### `MotionCommand compute_command(const Pose2D& current_pose, const Velocity& vel)`

**Purpose**  
Main control function, called at each control cycle.

**Inputs**
- `current_pose`: current robot pose from localization
- `vel`: current robot velocity (currently unused)

**Output**
- `MotionCommand` containing:
- Fixed target speed (m/s)
- Steering command in **servo degrees**

If no valid path exists or the goal is reached, a **stop command** is returned.

---

### `bool is_path_complete()`

Checks whether the robot is within a tolerance radius of the final waypoint.  
Currently not critical, as paths are continuously refreshed.

---

## Limitations & Future Improvements

- Replace fixed speed with proper **velocity PID control**
- Enable **adaptive lookahead distance**
- Add a **local obstacle-aware planner** on ESP2
- Improve steering smoothness and curvature-based speed modulation

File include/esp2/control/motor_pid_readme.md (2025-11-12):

# **Motor Velocity PID Controller**

A time-based PID controller designed for the closed-loop velocity control of the SLAM car's drive motor.
Its primary role is to take a **target velocity** (from the Pure Pursuit algorithm) and a **current velocity** (from odometry/sensor fusion) and compute the exact motor PWM signal required to make them match. (Adjust the current velocity to match the target velocity.)

## **Core Principles \- How This PID Works**

A PID controller works by calculating a "control signal" based on three terms, which correct for past, present, and future errors. The goal is to **minimize** the error between the target and current velocities.

### **1\. Proportional (P) \- The Present**

* **Concept**: This term provides a response that is proportional to the **current error**.  
* **Equation**: Error \= TargetVelocity \- CurrentVelocity  
* **Behavior**: If you are far from your target speed, the P-term gives a large correction. If you are close, it gives a small one. It's the main "driving" force of the controller.
* **Limitation**: By itself, a P-only controller often results in a **steady-state error**. For example, when going up an incline, the P-term alone might not be strong enough to ever reach the *full* target speed. Genreally speeking, it will often result in oscillation and *long* convergence time to it's target speed.

### **2\. Integral (I) \- The Past**

* **Concept**: This term looks at the **accumulation of past errors**. It sums up all previous errors and multiplies them by the time they persisted (dt).  
* **Behavior**: If the P-term consistently fails to reach the target (causing a small, persistent steady-state error), this integral\_ sum will grow over time. This growth adds more and more power until the error finally becomes zero. This is what defeats steady-state error (like on our incline example). It accelerates the convergance.
* **Key Feature (Anti-Windup)**: This implementation includes "integral anti-windup." The integral\_ term is "clamped" (limited) to a PID\_INTEGRAL\_MAX value. This prevents it from growing to a massive, unstable value if the car gets stuck, which would otherwise cause extreme overshooting. (e.g. wheel slipping, steep incline, human holding the car, etc.)

### **3\. Derivative (D) \- The Future**

* **Concept**: This term provides a response proportional to the **rate of change of the error**. It's essentially predicting the *future* error.  
* **Behavior**: The D-term acts as a damper, smoothing the controller's response.  
  * If the car is approaching the target speed *very quickly* (error is closing fast), the D-term will apply a "braking" force to prevent overshooting.  
  * If the car is suddenly knocked away from its target (like hitting a bump), the D-term provides a quick boost to counteract the disturbance.  
* It makes the controller more stable,  **less prone to oscillation**.

### **Final Output**

The final control signal is the sum of these three terms:  
$ControlSignal = (K_p * Error) + (K_i * Integral) + (K_d * Derivative)$
This ControlSignal (a float value, clamped between \-1.0 and 1.0) is then scaled by this class to the precise PWM pulse width required by the ESC (e.g., 1000µs for full-reverse, 1500µs for neutral, 2000µs for full-forward).

## **Implementation Details**

* **motor\_pid.h**: Defines the MotorPID class, its constructor, public methods (`compute_pwm_output`, `reset`), and private member variables (the gains `Kp_`, `Ki_`, `Kd_` and the state variables `integral_`, `prev_err_`).  
* **motor\_pid.cpp**: Implements the class logic.  
  * **Time-Based (dt)**: All integral and derivative calculations are multiplied or divided by `dt` (the time delta in seconds). This makes the controller's behavior consistent, regardless of the loop's frequency.
  * **Direct PWM Output**: This class handles all the math. You give it velocities, and it gives you back the exact MotorOutputs (`uint16_t`) PWM value to send to the MotorController.

## **API Usage**

Here is a basic example of how to integrate the MotorPID into the main control loop.  
```
#include "motor_pid.h"  
#include "MotorController.h"  
#include "common/data_types.h"

// 1. Define your tuned gains
// THESE GAINS MUST BE TUNED AND WILL TAKE A LOT OF TIME TO DO SO!
#define KP 1.5  
#define KI 0.8  
#define KD 0.2

// 2. Instantiate your PID controller and Motor  
MotorPID motor_pid(KP, KI, KD);  
MotorController motor_controller(MOTOR_PWM_PIN);

// 3. Keep track of time  
unsigned long last_loop_time = 0;

void setup() {  
    motor_controller.begin();  
    last_loop_time = micros();  
}

void loop() {  
    // --- 1. Timing ---  
    unsigned long now_us = micros();  
    float dt = (now_us - last_loop_time) / 1000000.0f; // dt in seconds  
    last_loop_time = now_us;

    // --- 2. Get Inputs ---  
    // (Get these from Pure Pursuit and Odometry/EKF)  
    Velocity target_vel;  
    target_vel.v_linear = 1.0; // Target 1.0 m/s

    Velocity current_vel;  
    current_vel.v_linear = 0.8; // Measured 0.8 m/s

    // --- 3. Compute ---  
    // The PID controller does all the hard work  
    MotorOutputs pwm_signal = motor_pid.compute_pwm_output(target_vel, current_vel, dt);

    // --- 4. Actuate ---  
    motor_controller.setTargetUs(pwm_signal);  
    motor_controller.update(); // Call this to apply the new PWM value  
}
```

### **Public Methods**

* MotorPID(float Kp, float Ki, float Kd)  
  * The constructor. Initializes the PID gains.  
* MotorOutputs compute\_pwm\_output(const Velocity& target\_vel, const Velocity& current\_velocity, float dt)  
  * The main computation function. Call this once per loop.  
* void reset()  
  * Resets the controller's internal state (integral\_ and prev\_err\_). Call this if the PID is disabled for a period to prevent it from acting on stale data.

## **Tuning**

The gains Kp, Ki, and Kd, as well as the integral clamp limits (PID\_INTEGRAL\_MIN/MAX), are critical to the car's performance. These values **must** be tuned experimentally for the specific physics (weight, friction, motor power) of your car.

## **Resources**

* Good intuition course on youtube: https://www.youtube.com/playlist?list=PLn8PRpmsu08pQBgjxYFXSsODEF3Jqmm-y  
* Aplication to a "wall following" controller in F1TENTH course: https://youtu.be/qIpiqhO3ITY?si=5K6qbe66yPaF3mj-
*

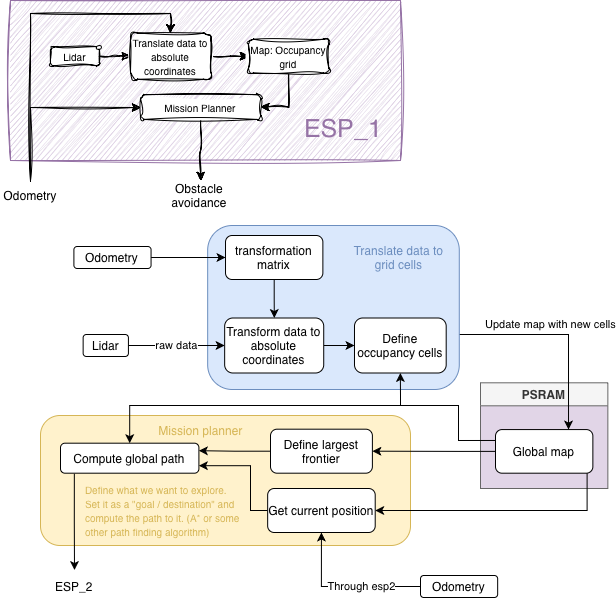
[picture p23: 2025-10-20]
assets/docs/esp1/esp1-architecture.png

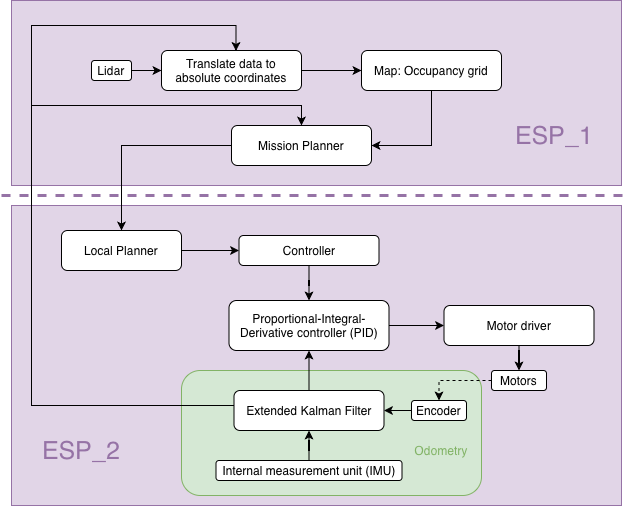
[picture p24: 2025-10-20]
assets/docs/global-architecture.png

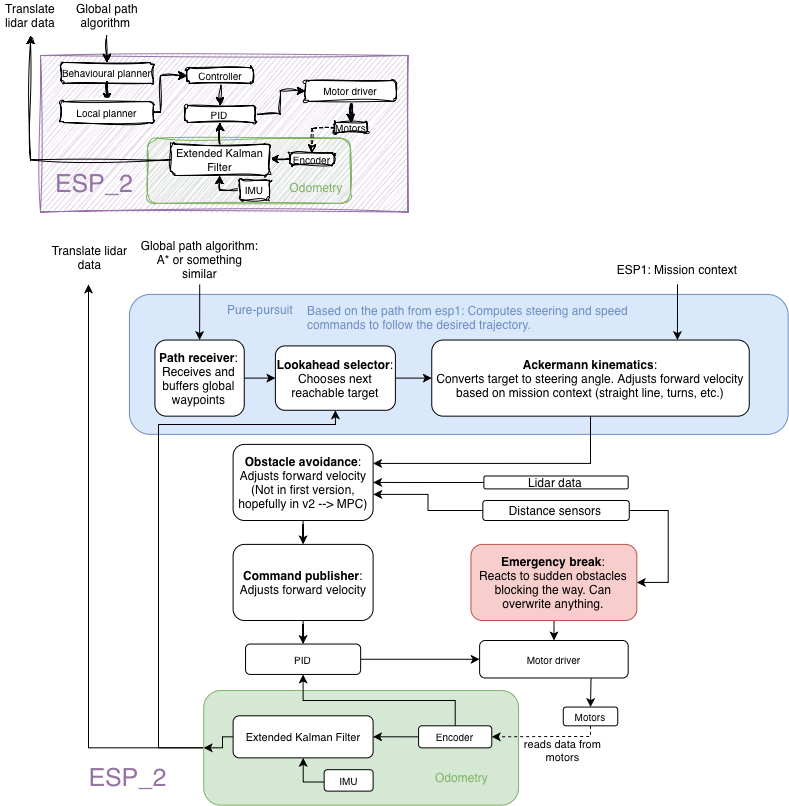
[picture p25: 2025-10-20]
assets/docs/esp2/esp2-architecture.png

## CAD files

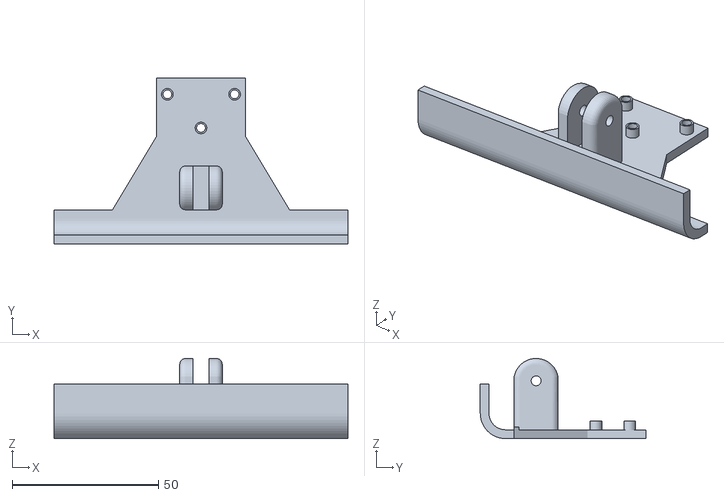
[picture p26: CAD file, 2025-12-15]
assets/docs/hardware/CAD/bumper_and_carattach.stl
100.6 x 56.6 x 27.4

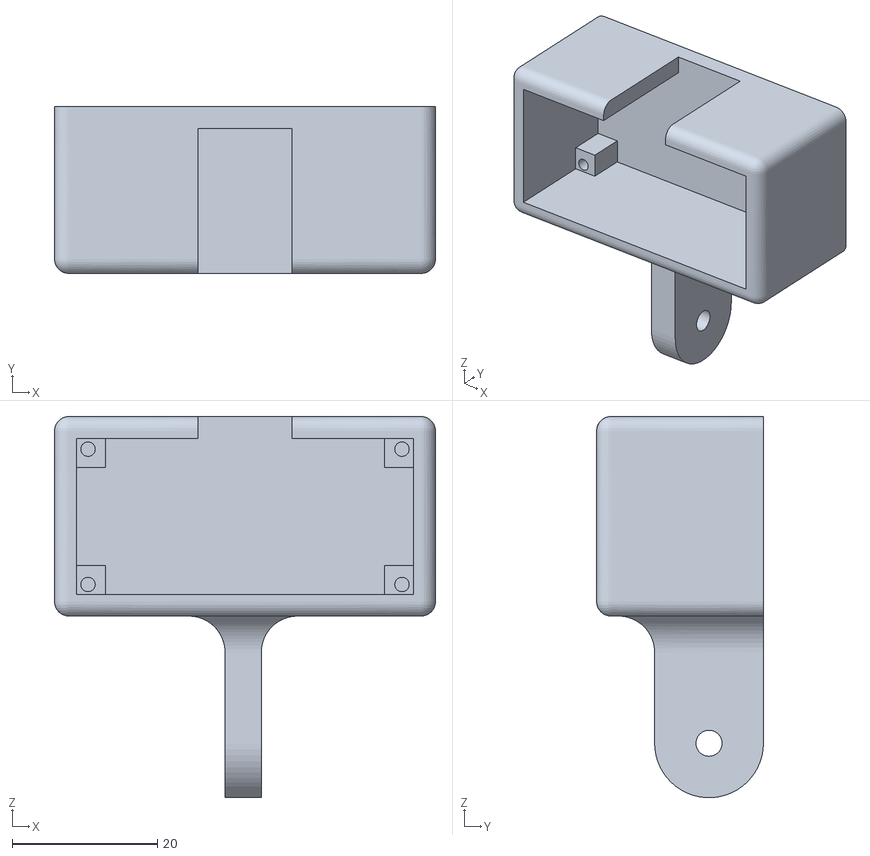
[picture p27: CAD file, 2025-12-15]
assets/docs/hardware/CAD/ultrasonicsensor_case.stl
52.5 x 23.0 x 52.5

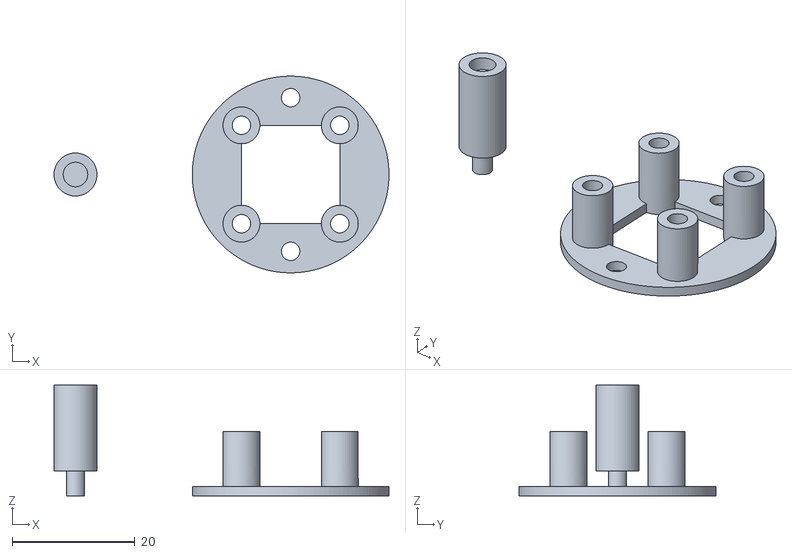
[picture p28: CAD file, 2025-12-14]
assets/docs/hardware/CAD/encoder_support.stl
54.5 x 32.0 x 18.0

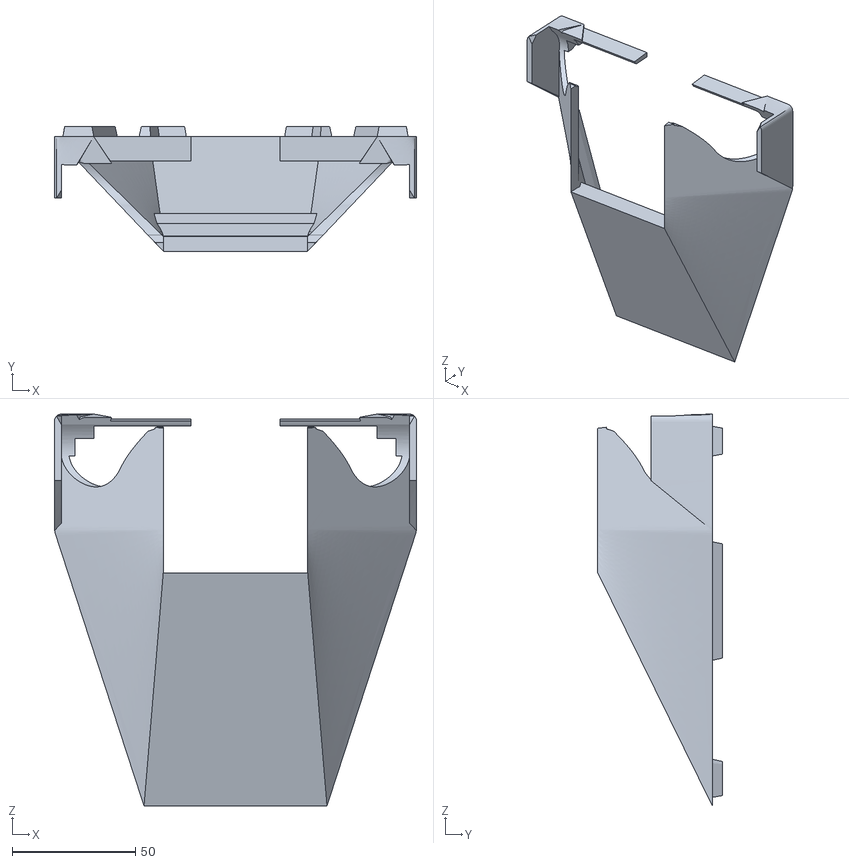
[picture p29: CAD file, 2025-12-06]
assets/docs/hardware/CAD/MIT_roof.stl
147.0 x 50.5 x 159.0

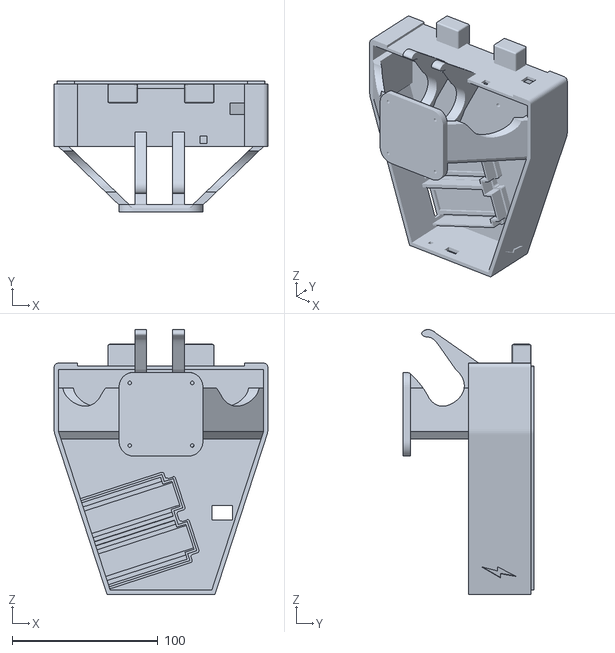
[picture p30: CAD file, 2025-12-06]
assets/docs/hardware/CAD/MIT_car_body.stl
147.0 x 90.0 x 182.1

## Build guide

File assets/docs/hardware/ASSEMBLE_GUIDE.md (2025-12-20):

🏠 [Backlink to the main README](/README.md)

# How to Assemble

To begin, assemble the mechanical base of the car following the official [Tamiya Blitzer Beetle manual](https://www.tamiyausa.com/media/files/58502ml-829-5367.pdf).
We only need the minimal mechanical build so the car can drive, skip the decorative carcass.

**Step 1: Build the Car**  
- Assemble the chassis according to the manual.  
- Mount the steering servo inside the chassis.  
- Ensure the servo cables are routed through the rectangular opening so they can later connect to the ESP.  

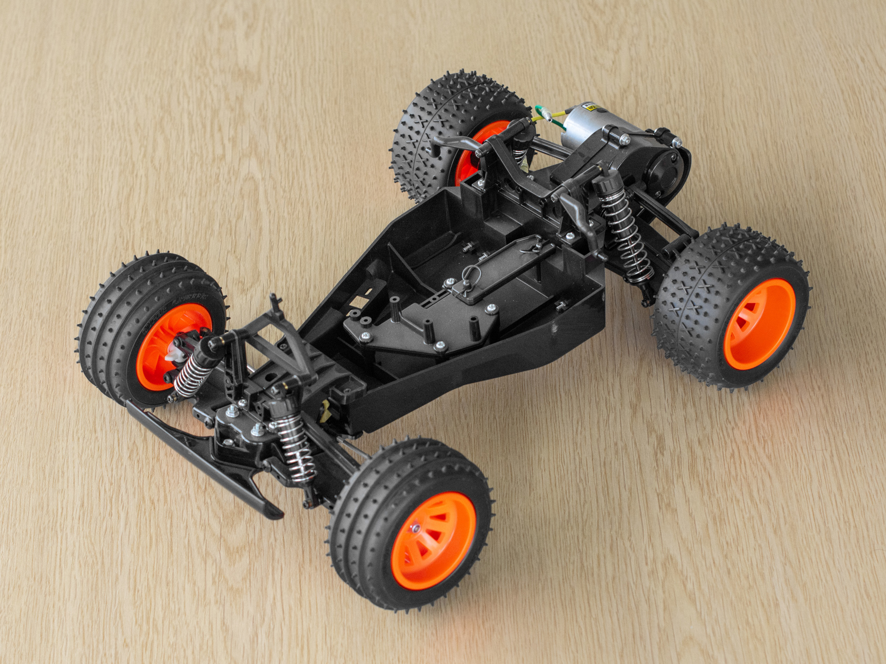
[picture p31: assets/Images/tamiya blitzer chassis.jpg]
Chassis


**Step 2: Encoder Mount + Magnet**  
- 3D‑print the encoder mount [CAD file](/assets/docs/hardware/CAD/).  
- Attach the mount in front of the motor.  
- Fix the encoder magnet directly onto the motor shaft as shown in the provided image.  
- This ensures accurate rotation measurement.  
- Then screw down the encoder on its mount.

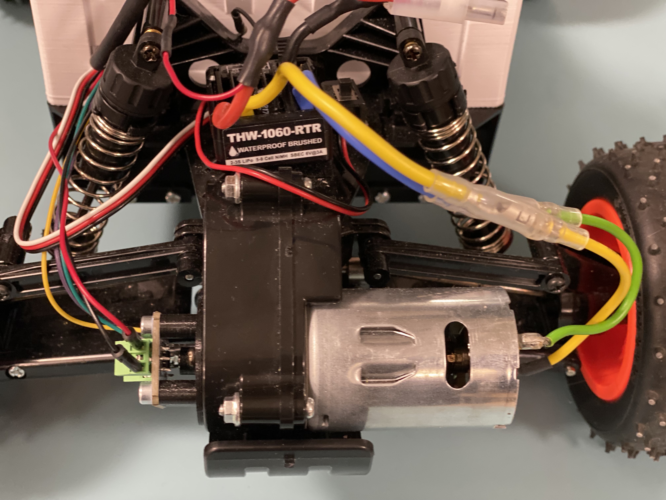
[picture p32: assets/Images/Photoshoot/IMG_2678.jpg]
Encoder + Magnet


**Step 3: Layer Platform (ESP + Lidar Holder)**  
- Place the 3D‑printed platform on the chassis.  
- This platform integrates holders for both ESP boards and the lidar.  
- Screw the lidar onto its holder first (space is tight, so it’s easier to mount before other components).  
- Then screw down the buck converter and IMU onto their designated spots.  

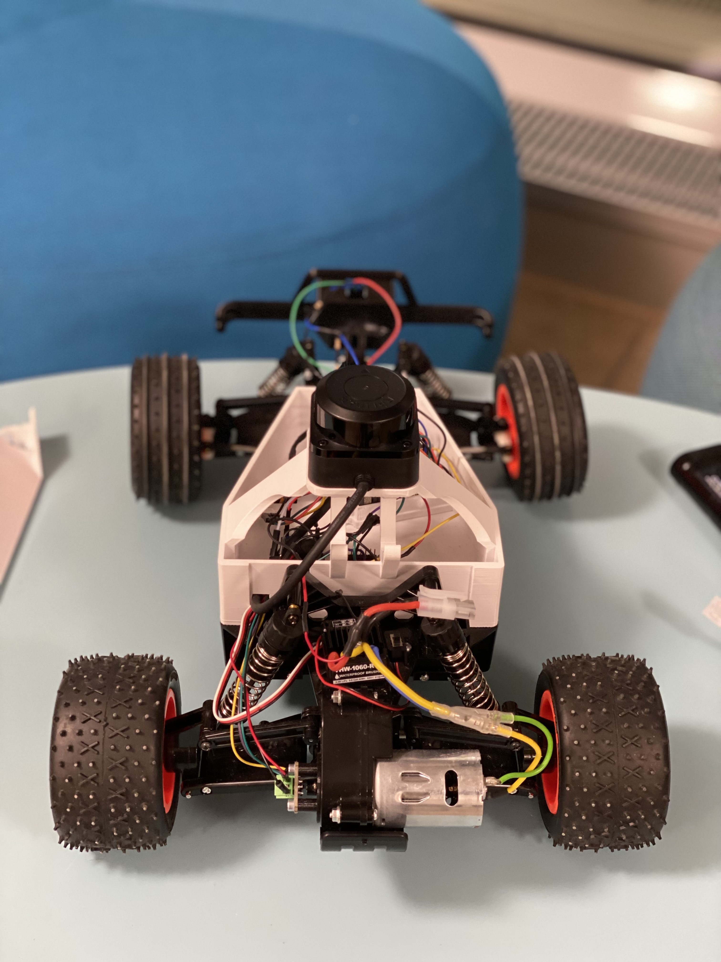
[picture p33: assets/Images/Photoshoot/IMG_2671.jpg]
Lidar


**Step 4: Mount the ESP Boards**  
- Place ESP1 and ESP2 onto the platform.  
*Improovement note: mount both microcontrollers facing **upwards** so their LEDs and reset buttons are visible.*
- Our current ESP1 faces down, which hides the LEDs and complicates troubleshooting.  

<p align="center">ESPs</p>

**Step 5: Ultrasonic Sensor Mount**  
- Attach the front 3D‑printed piece designed for the ultrasonic sensor at the front of the car.  
- Screw the sensor securely into the mount.  

<p align="center">Ultrasonic mount</p>
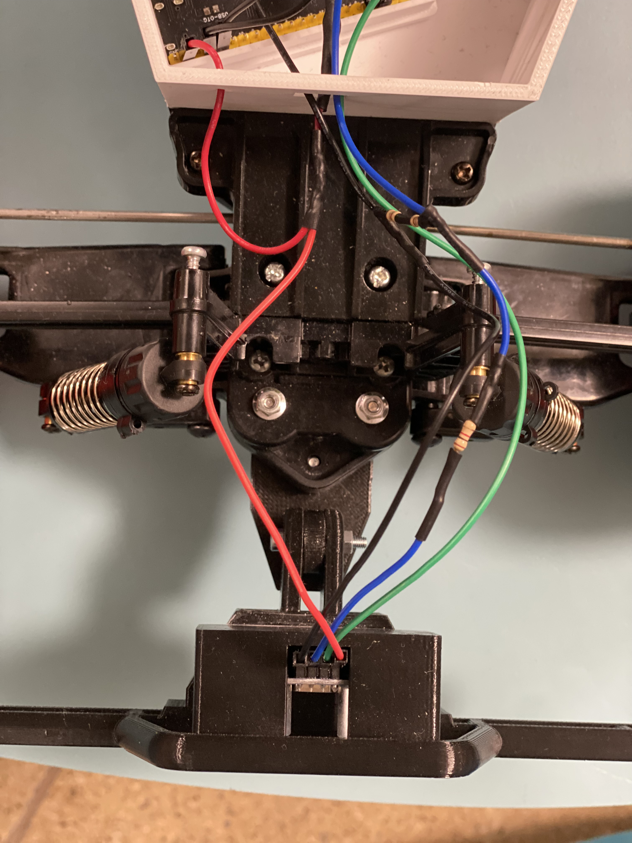
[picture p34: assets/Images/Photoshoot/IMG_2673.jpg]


**Step 6: Final Assembly**  
- Place the hood/top of the car back on.  
- Insert the battery into its dedicated slot the hood design holds it firmly and stabilizes it during motion.  
- Double‑check that all mounts are secure and cables are routed cleanly for wiring.  

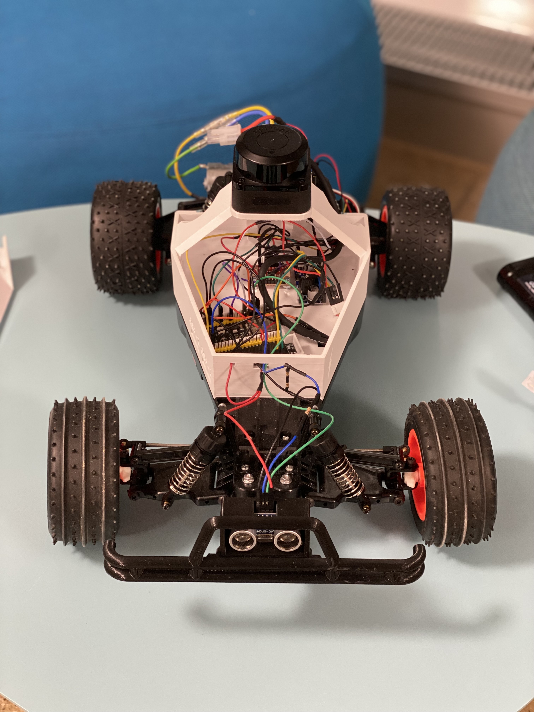
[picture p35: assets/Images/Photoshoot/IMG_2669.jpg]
Front open view

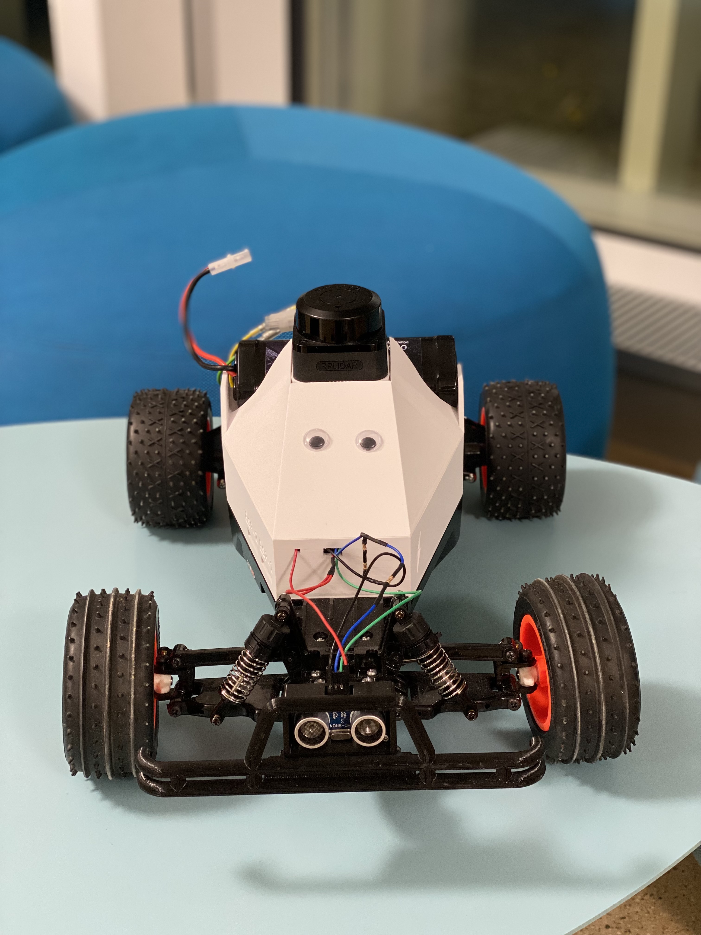
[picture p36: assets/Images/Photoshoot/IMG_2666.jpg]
Front closed

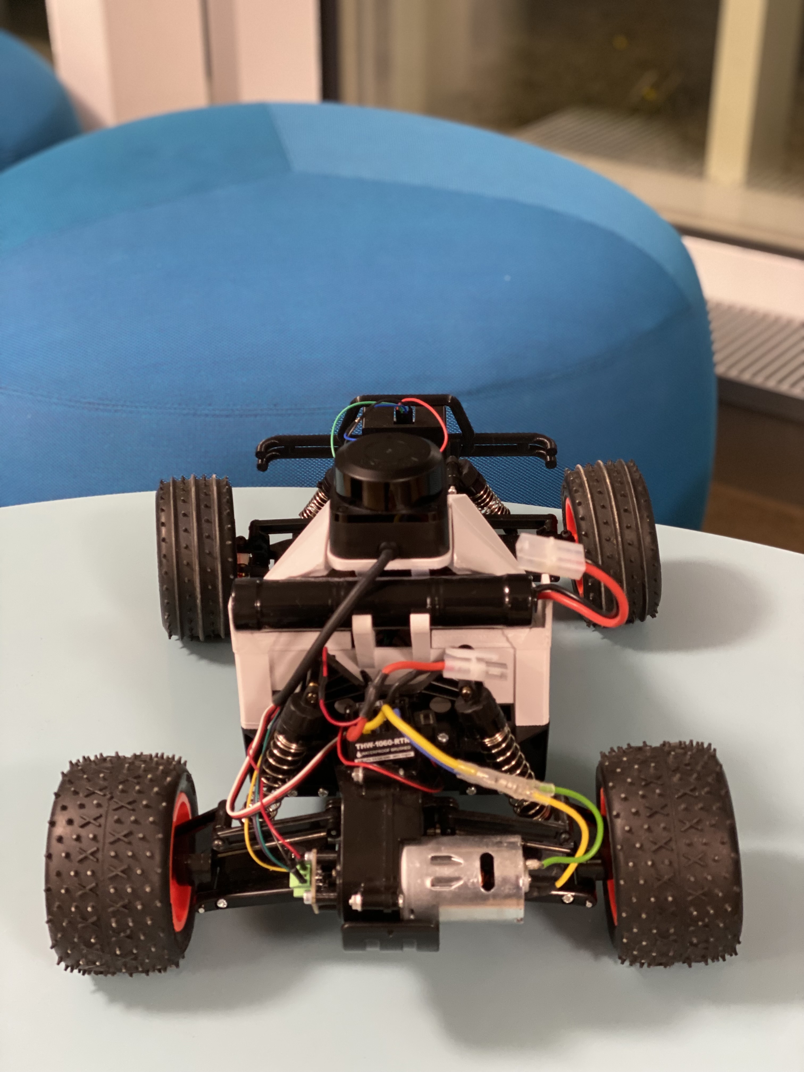
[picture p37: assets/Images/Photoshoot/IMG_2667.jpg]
Back with battery


**Step 7: Wiring**  
- Once the mechanical build is complete, proceed to the [Soldering & Wiring](#soldering--wiring) section.  
- Follow the circuit [diagram](/assets/docs/hardware/circuit/slamaleykoum_electrical_circuit.drawio.png) for all connections.  

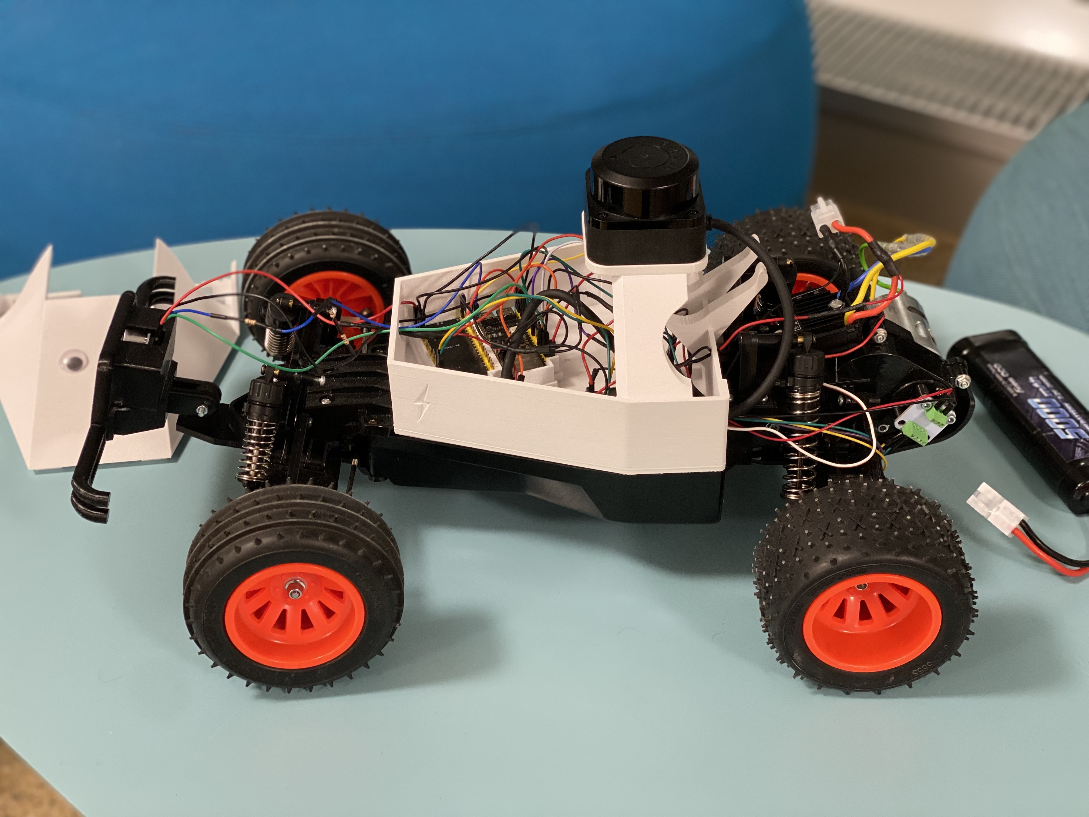
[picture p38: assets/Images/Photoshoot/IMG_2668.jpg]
Side view open


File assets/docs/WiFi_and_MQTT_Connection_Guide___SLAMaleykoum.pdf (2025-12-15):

# WiFi and MQTT Connection Guide SLAMaleykoum

Alex Dorsaz

October 2025

## 1 WiFi Connection

- Go on the parameters of your laptop HotSpot and make sure your network bandwidth is set to 2.4 Hz (ESP32 doesn’t support 5 Hz). On Windows and MacOs, it is by default set on 5 Hz, so you must change it.

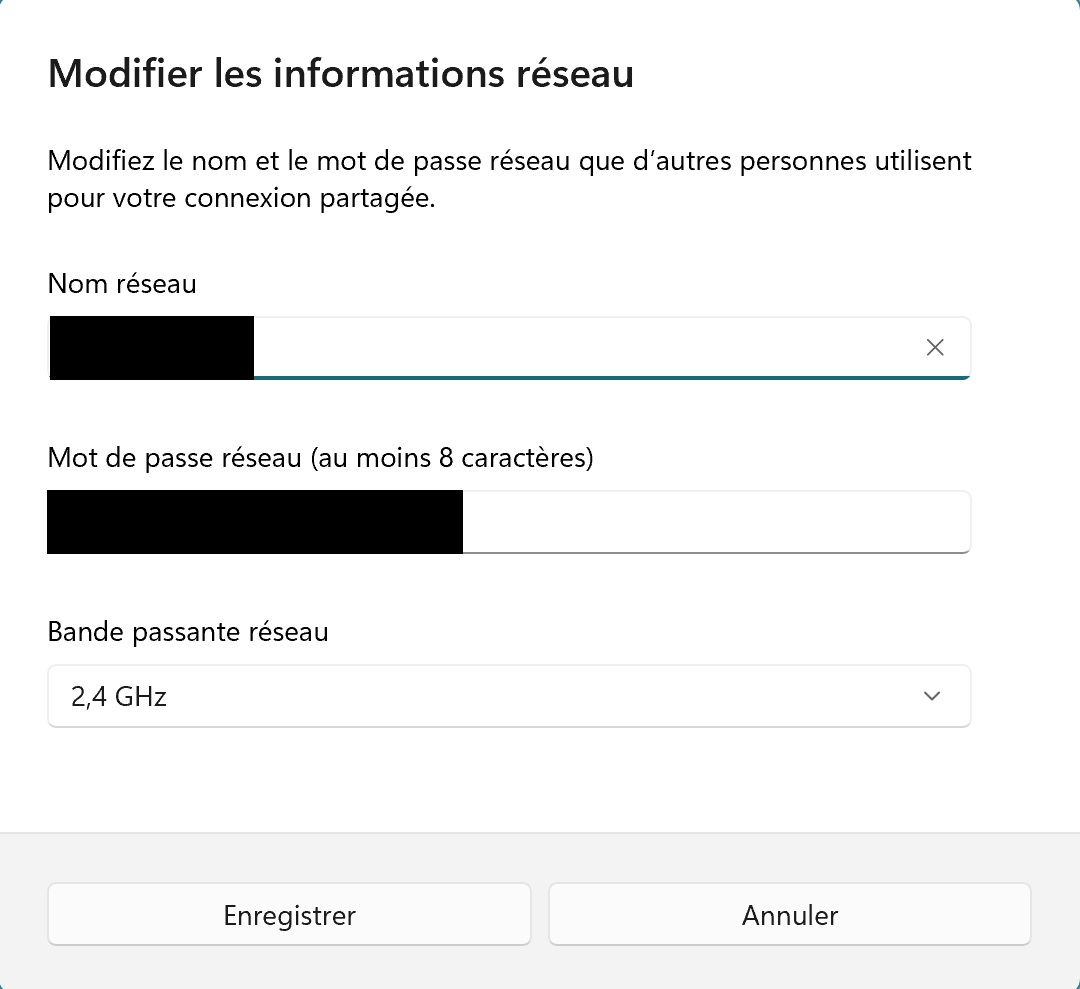
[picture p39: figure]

- Enable the Wifi HotSpot of your Laptop. Make sure you have a stable Wifi connection before.
- In ”wifi connection.h”, change the variables ”ssid” and ”pass” into respectively your HotSpot name and HotSpot password.

1

- Define the correct pin for the test ”test connection” in ”test main” of one of the ESP.
Connect your laptop to the corresponding ESP and run the command pio
run -e esp2 test -t upload && pio device monitor in a PlatformIo terminal.
You should now have a success in your terminal when you run the ”test connection.cpp” file on the ESP 2 which means you should obtain something like this :

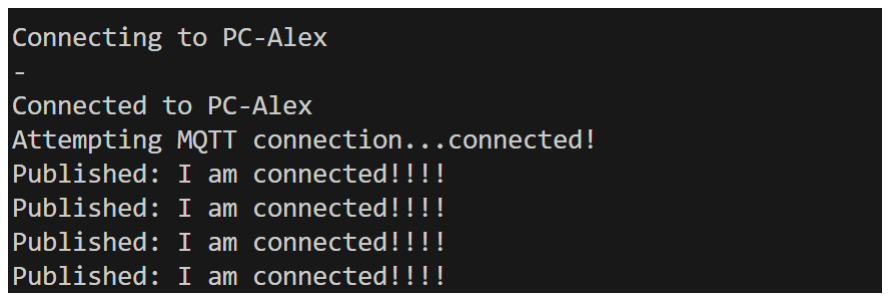
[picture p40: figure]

## 2 MQTT Connection

The ESP32 should establish the MQTT connection automatically with the parameters given. This means that it connects to the broker ”broker.hivemq.com” with the port 1883.
Now, to get the data send by the ESP32 to the broker, you need to connect to the broker on your laptop.

### 2.1 MQTT Explorer

In order to get simple data like print or few values like distance to a sensor for every loop, you can simply use MQTT Explorer.

- Download the version you need here : MQTT Explorer (https://mqtt-explorer.com/)
- Then, open MQTT Explorer and add a new connection. Setup the MQTT Connection like this :

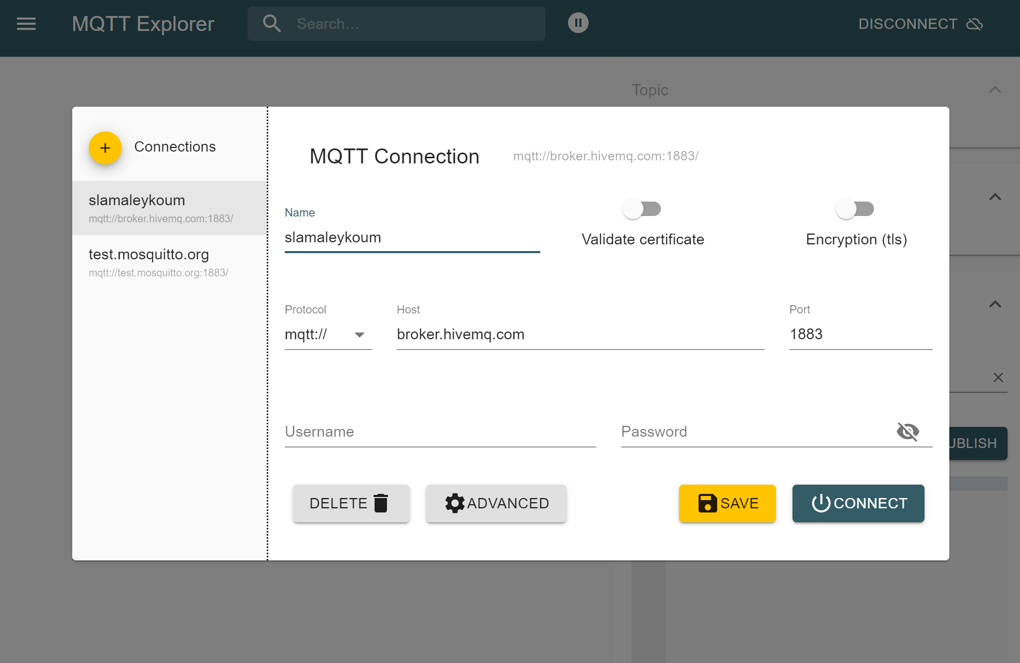
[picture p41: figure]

2

- In order to get the messages and to be able to send commands, you need to create the topics.
Go to the section ”Advanced” and add the topics you want to see. They all begin by ”slamaleykoum77/” and end with the name of the topics known: ”print” (for simple debug messages), ”imu”, ”ultrasonic”, ”encoder”, ”servo”, ”lidar”.

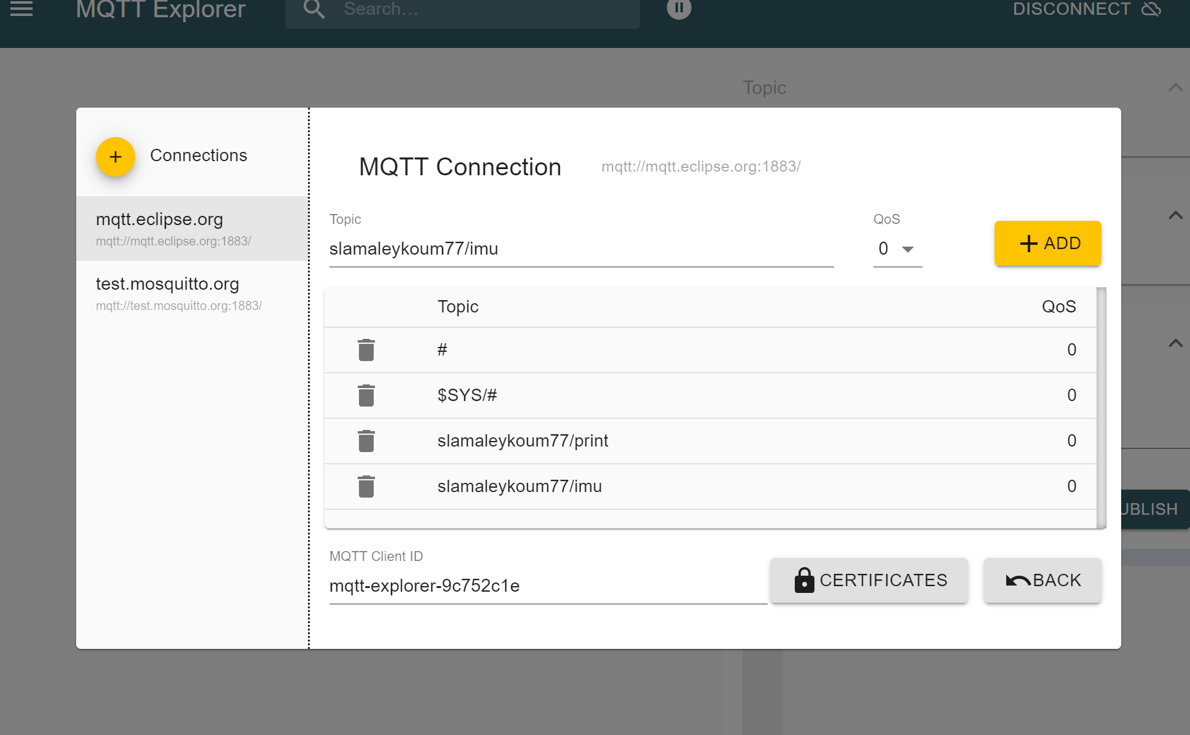
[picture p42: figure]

- Then, click on ”connect” and you should start to receive the messages of the SLAM car.
PS : you must have uploaded the code on the ESP32 and connected the battery to the SLAM car (be careful to not be connected with a cable to the ESP32 with your computer and still have your HotSpot activated !). Also, follow the last point and make sure you upload your messages to the correct topics in your test code.
- If you want to get the previous values of a topic, you can simply click on it and go to the tab ”History” on the right panel. You will get all the values you got with the time when you received them.

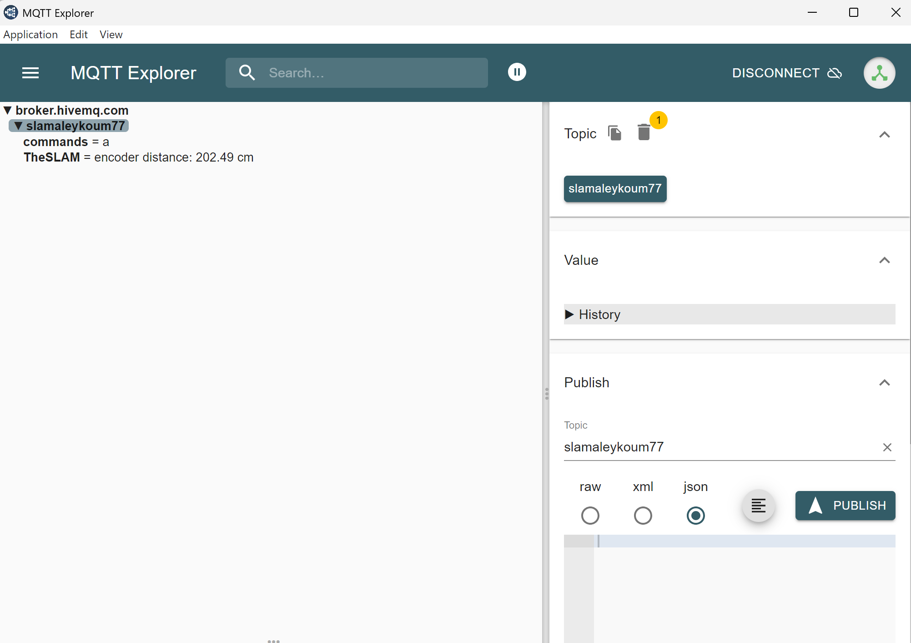
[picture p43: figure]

3

- In order to send data of the code, you must have this in your code:

– In the setup function, make sure to have this line: connection.setupWifi();.

– In the loop function, you must have this line:
connection.check connection();.

– To send a message, you must create a message (char*) and then publish it to the broker with the command:
connection.publish(mqtt topic, msg);.
Make sure to upload them on the topic you want.

Here is an example for the connection test:

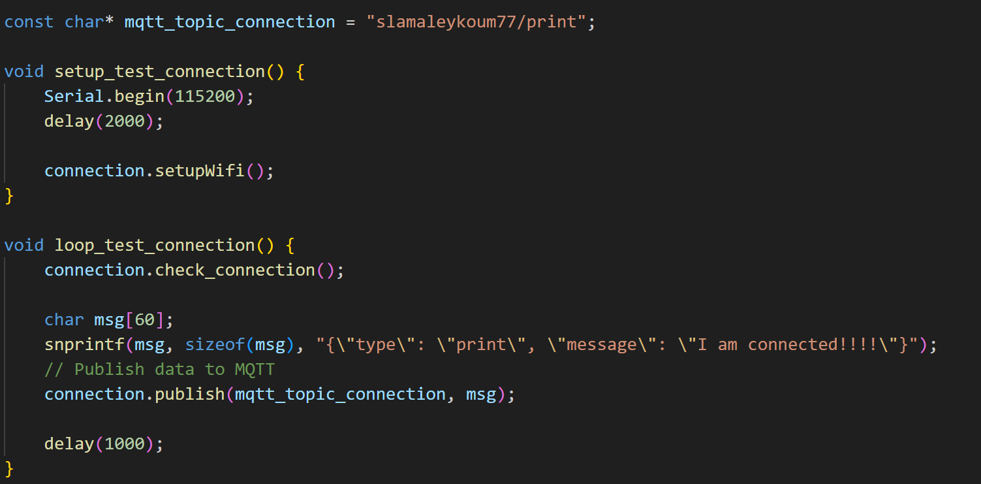
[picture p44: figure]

### 2.2 The file mqtt client.py

To get more data or if you prefer simple prints in a terminal, you can directly use a Python file that connects to the broker and prints what you want.
In the directory ”2025fa-SLAMaleykoum”, the file ”mqtt client.py” is doing this.
- Make sure you have Python installed and then install the paho-mqtt library with the command:
pip install paho-mqtt matplotlib
- Just like before, when you have uploaded your code to one of the ESPs, you just have to run this Python file in a terminal (not PlatformIO) with the command:
python mqtt client.py
It will connect to the broker and catch all the messages sent by the ESPs.
- The file should print all the values received in any of the topics known and print it in the terminal. You can improve it in order to get the data printed as you want or in a different manner (use ”plt” if you want to plot a curve with some distances received for example).

4

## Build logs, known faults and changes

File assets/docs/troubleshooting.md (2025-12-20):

🏠 [Backlink to the main README](/README.md)

## Recommendations

### Common ESP1 & ESP2

#### Hardware

**Hardware wear and wiring issues:**

Reused components had weak solder joints and loose connectors, causing intermittent failures (especially the encoder).

**Fix**: Replaced fragile connectors with screw terminal blocks → stable signals.

**Recommendation**: Inspect wiring early, re-solder weak joints, standardize connectors, and consider a small PCB for reliability.

#### Software

**Wi-Fi communication issues:**

MQTT introduced significant latency and was unable to reliably transmit the full Bayesian map, while TCP streams sometimes produced incomplete or corrupted data.

**Fix**: MQTT was used only for basic hardware debugging due to its simplicity. For debugging and transmitting complex algorithms and large data structures, a TCP server was implemented and a custom Python client was used to retrieve and visualize data from the ESP32. When errors occurred in the final map, task priorities were reviewed and mutexes were added to protect shared resources in FreeRTOS.

**Recommendation**: Consider using UDP instead of TCP when occasional packet loss is acceptable, but ensure proper packet structuring, ordering, and validation to maintain data consistency.

### ESP1-Specific Issues

#### Hardware

**LiDAR serial initialization:**

Difficulty starting the LiDAR due to incorrect `RX/TX pin` configuration.

**Fix**: Ensured the ESP32 RX pin in the code matched the physical LiDAR TX connection.

**Recommendation**: Clearly document pin assignments and validate serial communication with minimal test code first. If the pins you selected don't work, it might be that they are broken on the ESP. Try other pins RX/TX.

#### Software

**High LiDAR data throughput:**

MQTT could not handle the volume of scan data, causing delays and packet loss.

**Fix**: Configured the ESP32 as a Wi-Fi access point with a TCP server and streamed data to a Python client for real-time visualization.

**Recommendation**: Evaluate data bandwidth early and choose TCP/UDP streaming over MQTT for high-frequency sensor data.

---

**Latency and incomplete scans:**

Attempting to process every LiDAR point introduced lag and instability.

**Fix**: Implemented downsampling (one point every 5, or one scan every 3), maintaining accuracy while reducing load.

**Recommendation**: Always include configurable downsampling and monitor real-time latency.

---

**LiDAR buffer decoding and angle conversion:**

Incorrect parsing and degree/radian mismatches caused distorted maps.

**Fix**: Carefully decoded LiDAR buffers and standardized angle units throughout the pipeline.

**Recommendation**: Check the documentation of your LiDAR, centralize unit conversions and validate data using simple geometric test cases.

---

**Bayesian occupancy grid performance:**

Grid computation was initially too heavy for the ESP32.

**Fix**: Optimized grid size and resolution to match the Python visualization and fit ESP32 memory constraints.

**Recommendation**: Design mapping resolution based on hardware limits and test memory usage early.

---

**Mission Planner boundary detection:**

Defining meaningful exploration boundaries was ambiguous.

**Fix**: Defined boundaries as white cells adjacent to gray cells, clustered them, and selected the closest valid cluster (≥8 cells).

**Recommendation**: Use simple, well-defined heuristics for boundary detection and validate them visually.

---

**Global Planner (A*) efficiency:**

For the **Global Planner**, the problems encountered were mainly related to the efficiency of the **A-Star algorithm**. We limited the number of waypoints to a maximum of 5 and evenly distributed them along the found path. We decided to use a heuristic function with the distance from the current point to the goal to find the optimal path as quickly as possible.

Unrestricted A* planning was computationally expensive.

**Fix**: Boost the heuristic function to search the path

**Recommendation**: If your ESP32 can compute it, add a Local Planner to make it more precise when it detects smaller objects

### ESP2-Specific Issues

#### Hardware

**Encoder jitter:**

The encoder produced noisy tick timing due to electrical noise, slight mechanical misalignment, and (before switching connectors) intermittent contact. This caused unstable velocity estimates, especially at higher speeds.

**Fix**: The AS5600 library (Rob Tillaart) was used to reject obviously invalid readings. While it does not smooth data, it prevented major miscalculations and improved low-speed velocity estimation.

**Recommendation**: Sample encoder at high, consistent rates; Use screw terminal blocks. Consider a wheel-mounted encoder for higher effective resolution (gearbox ratio ≈ 1:10 reduces motor-shaft resolution at the wheel).

---

**Motor PID control not feasible:**

The stock THW-1060-RTR ESC only provides discrete throttle steps. Small PWM changes often produced no speed change, then suddenly jumped to a higher speed. This made PID velocity control impossible, hence the controller oscillated and never converged.

**Fix**: PID control was abandoned; the car was operated at a constant low throttle.

**Recommendation**: Replace the ESC with an IBT-4 (BTS7960) motor driver for smooth PWM.

---

**IMU acceleration unreliable for odometry and EKF:**

Drift and bias made acceleration unreliable for odometry/EKF fusion.

**Fix**: Acceleration was deprioritized in favor of encoder-based velocity estimation.

**Recommendation**: Perform proper IMU calibration, apply bias estimation and low-pass filtering, and rely more heavily on gyroscope + encoder fusion rather than raw acceleration.

#### Software

**Odometry breakdown at higher speeds:**

At higher speeds, the combination of encoder jitter, IMU drift, and discrete ESC throttle steps caused odometry to diverge. The car eventually lost track of its position.

**Fix**: No full fix was possible with the existing hardware. The car was limited to one of its slowest stable speeds.

**Recommendation**: Verify whether the odometry task is running fast enough and with high priority.

---

**IMU yaw jump filtering:**

The IMU occasionally produced sudden yaw jumps, which corrupted the estimated pose sent to ESP1 and affected how the Bayesian map was built.

**Fix**: A yaw-stability filter was implemented: ESP2 only stores and transmits its position if the yaw change is ≤ 15° between updates. This prevented corrupted odometry packets from polluting the global map.

**Recommendation**: Always include sanity checks on IMU orientation.

## Troubleshooting

If you encounter issues, check the list below before reaching out.

| Problem | Possible Cause | Solution |
| :--- | :--- | :--- |
| **Map has "fuzzy" walls** | The environment might contain windows, or reflective surfaces, maybe even the obstacles are too thin or the walls have holes in them (mesh / fence) | Since the lidar can't correctly detect those kinds of objects, try mapping something else |
| **WiFi doesn't appear** | You cannot flash the ESP32 from the left port, hence the code was never uploaded OR you might have uploaded the code of the ESP2 on the ESP1, it happens way too often | Flash the ESPs again, with their respective code on their RIGHT port (In our setup, it's the center ports, since the ESP1 is upside-down) |
| **Wheels turn, car doesn't move** | The motor doesn't get any power | The ESC must be switched on immediately after connecting the battery |
| **ESP doesn't initialize or crashes often** | Cables might have come loose | Double check the pin connections |
| **ESP keeps crashing** | Battery might be too low | Check the battery level, charge it |
| **Map is not displaying but python code is up** | Incoherent map sizes | Double check the values in the `ground_station.py` file and the rest of the code, for the size of the map (grid size) and their max bounds are the same |
| **ESP1 crashes immediately** | The map size is too big | Reduce the map size. Note: The max nb of cells we managed to run with is 70x70 but if the real world size is not enough, you can increase the `RESOLUTION` value which will increase what each cell represents in the real world |

### Hardware Issues

**Symptom: Wheels spin but car doesn't move**

**Causes:**
1. ESC not powered
2. Battery voltage too low
3. Motor pinion gear not meshing

**Fixes:**
1. Turn ESC ON immediately after battery connection
2. Charge battery (check voltage >6.5V)
3. Adjust motor mount (should hear gear engagement)

---

**Symptom: Servo jitters or doesn't respond**

**Causes:**
1. Insufficient power (voltage drop)
2. PWM signal noise
3. Loose servo horn

**Fixes:**
1. Check buck converter output (should be 5V ±0.2V)
2. Add capacitor (100μF) across servo power pins
3. Tighten servo horn screw

---

**Symptom: Encoder reads constant zero**

**Causes:**
1. Magnet too far from sensor (>3mm gap)
2. I2C connection issue
3. Wrong I2C address

**Fixes:**
1. Adjust encoder mount (2-3mm gap optimal)
2. Verify SDA/SCL connections, check pull-up resistors
3. Run I2C scanner, confirm 0x36 address

---

**Symptom: ESP32 frequently crashes**

**Causes:**
1. Insufficient power
2. Stack overflow (task stack too small)
3. Watchdog timeout

**Fixes:**
1. Check battery voltage, verify buck converter stable
2. Increase `STACK_SIZE_*` in config
3. Add `vTaskDelay()` in long loops

### Software Issues

**Symptom: Map shows fuzzy/doubled walls**

**Causes:**
1. Reflective surfaces (glass, mirrors)
2. LiDAR seeing through thin obstacles
3. Odometry drift

**Fixes:**
1. Map in environment without windows
2. Avoid mesh fences, thin curtains
3. Recalibrate encoder, check IMU mounting

---

**Symptom: Robot ignores path commands**

**Causes:**
1. UART connection lost
2. Path message corrupted
3. Pure Pursuit stuck

**Fixes:**
1. Verify TX/RX wiring, check baud rate match
2. Enable CRC checking in ESP Link
3. Add timeout to reset Pure Pursuit state

### Emergency Procedures

**Robot stuck in infinite loop:**
1. Press emergency stop button (if installed)
2. Turn off ESC switch
3. Disconnect battery
4. Reflash ESP2 with safety limits

**Robot drives into obstacle despite ultrasonic:**
1. Check ultrasonic connections
2. Verify `EMERGENCY_THRESHOLD` not too small
3. Test sensor in isolation (upload test code)

**Cannot reflash ESP32:**
1. Try different USB cable (data, not charge-only)
2. Hold BOOT button while connecting USB
3. Use esptool.py directly:
   ```bash
   esptool.py --port /dev/ttyUSB0 erase_flash
   ```

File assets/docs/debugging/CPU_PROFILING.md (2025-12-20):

🏠 [Backlink to the main README](/README.md)

# CPU Profiling for ESP-1

## Overview

Real-time task profiling for ESP32 dual-core systems. Logs task execution events with microsecond precision to identify bottlenecks, mutex contention, and scheduling issues. In our case, to help us debug, we created our own profiling system to send the profiling data via TCP to our Ground Station.

**Why Profiling?**
- Detect CPU bottlenecks
- Debug mutex contention and deadlocks
- Validate task priorities and core pinning
- Prevent watchdog timer resets

## ESP1 Architecture

**8 FreeRTOS Tasks Across 2 Cores:**

| Core | Task ID | Name | Function |
|---|---|---|---|
| 1 | 1 | LIDAR | LiDAR data acquisition |
| 1 | 2 | SYNC | Pose-scan fusion |
| 1 | 3 | MAP | Bayesian grid updates |
| 0 | 4 | IPC | Inter-ESP communication |
| 0 | 5 | GPLAN | Global path planning |
| 0 | 6 | MPLAN | Mission planning |
| 0 | 7 | TCP | Telemetry transmission |
| 0 | 8 | VALID | Pose validation |

## How It Works

### 1. Event Logging (Firmware)

Each task logs START/END events to a circular buffer:

```cpp
void Bayesian_Grid_Task(void* parameter) {
    while (1) {
        log_event(ID_MAP, EVENT_START);  // Mark start
        
        // ... do work ...
        
        log_event(ID_MAP, EVENT_END);    // Mark end
        vTaskDelay(pdMS_TO_TICKS(50));
    }
}
```

**Data Structure (8 bytes/event):**
```cpp
struct TaskEvent {
    uint32_t timestamp_us;  // ESP32 micros()
    uint8_t task_id;        // 1-8
    uint8_t type;           // 1=START, 0=END
    uint8_t core_id;        // 0 or 1
    uint8_t padding;
};
```

### 2. TCP Transmission

The TCP task sends events to the ground station every 100ms. Uses critical sections to prevent race conditions during buffer copy.

### 3. Visualization

The ground station ([`ground_station.py`](/assets/docs/GROUND_STATION.md)) receives events and renders a live timeline showing task execution on both cores.

## Usage

### Quick Start

1. **Flash firmware** with profiling enabled (already included in your build)

2. **Connect to robot WiFi:**
   ```
   SSID: LIDAR_AP
   Password: l1darpass
   IP: 192.168.4.1
   ```

3. **Run ground station:**
   ```bash
   python ground_station.py
   ```

That's it! You'll see:
- Live map visualization
- Real-time task timeline (bottom of window)
- Task execution on both cores
- Performance metrics in HUD
- CSV log saved automatically

### What You'll See

**Timeline Panel (bottom):**
- Two horizontal lanes (Core 0 top, Core 1 bottom)
- Colored bars showing when each task runs
- Bar width = execution duration
- Gaps = task sleeping or blocked

**CSV Log:**
Automatically saved to `telemetry_trace_YYYYMMDD_HHMMSS.csv`:
```csv
Timestamp_PC,ESP_Time_us,Task_ID,Core,Event_Type
1702350445.123,1234567,3,1,1
1702350445.135,1246789,3,1,0
```

### Offline Analysis

Generate detailed Gantt charts from saved logs:

```bash
python plot_trace.py telemetry_trace_20241220_153045.csv
```

**Output:** High-resolution PNG showing task execution patterns

**Zoom to specific time window:**
```python
# In plot_trace.py:
ZOOM_WINDOW_SECONDS = 3.0    # Show 3 seconds
START_OFFSET_SECONDS = 2.0   # Starting at 2s mark
```

## Understanding the Output

### Live Timeline (Ground Station)

Note: Observe the lower part of the screen recording.


- **Horizontal bars** = task execution
- **Bar color** = task type (see legend)
- **Bar width** = execution time
- **Vertical position** = task ID
- **Panel** = CPU core

### Gantt Chart (Offline Analysis)
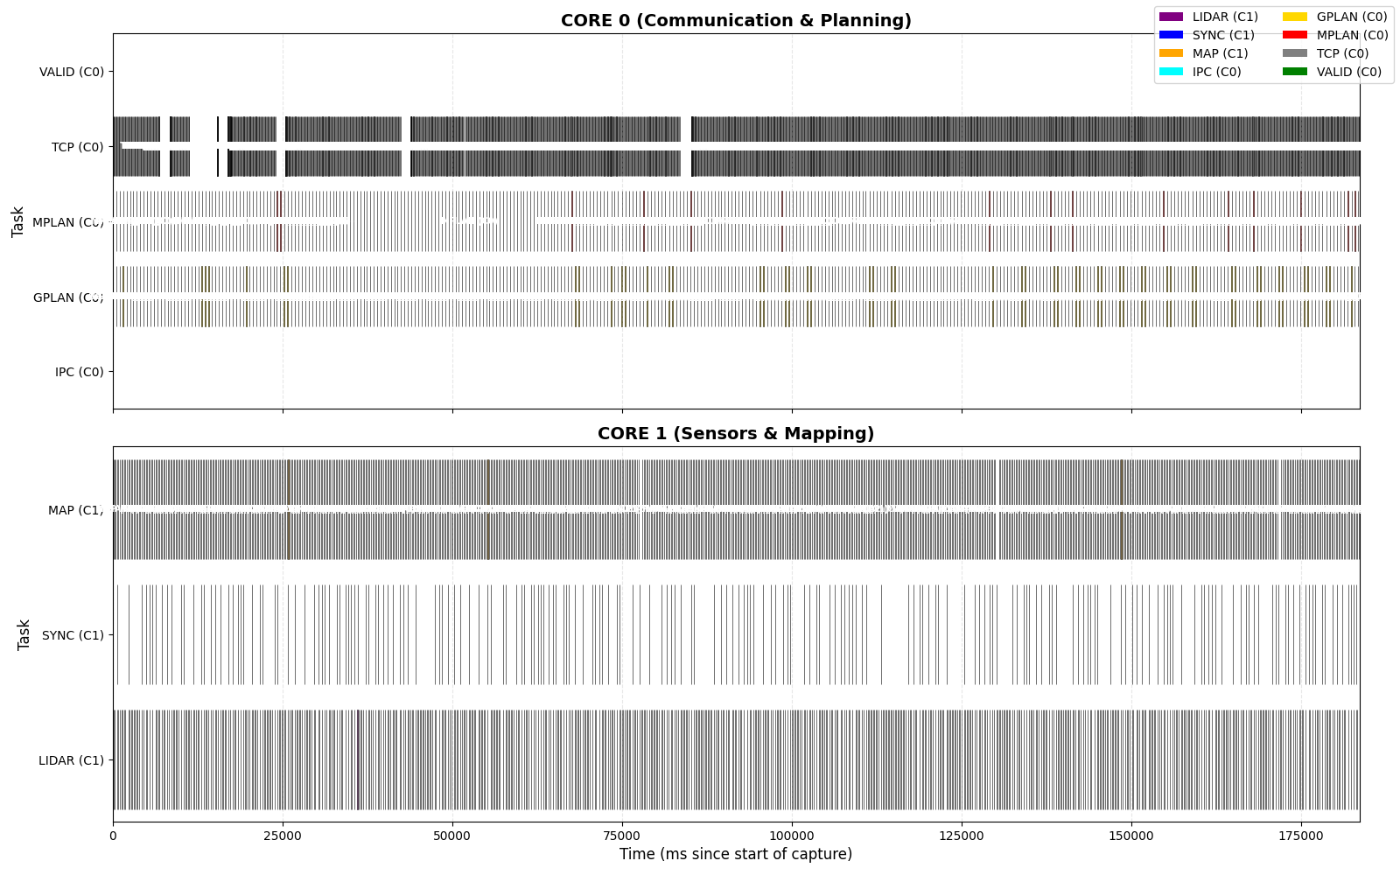
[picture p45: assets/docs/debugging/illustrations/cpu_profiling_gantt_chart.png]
Gantt Chart


Once you zoom in on a specific area you see it a lot more clearly.
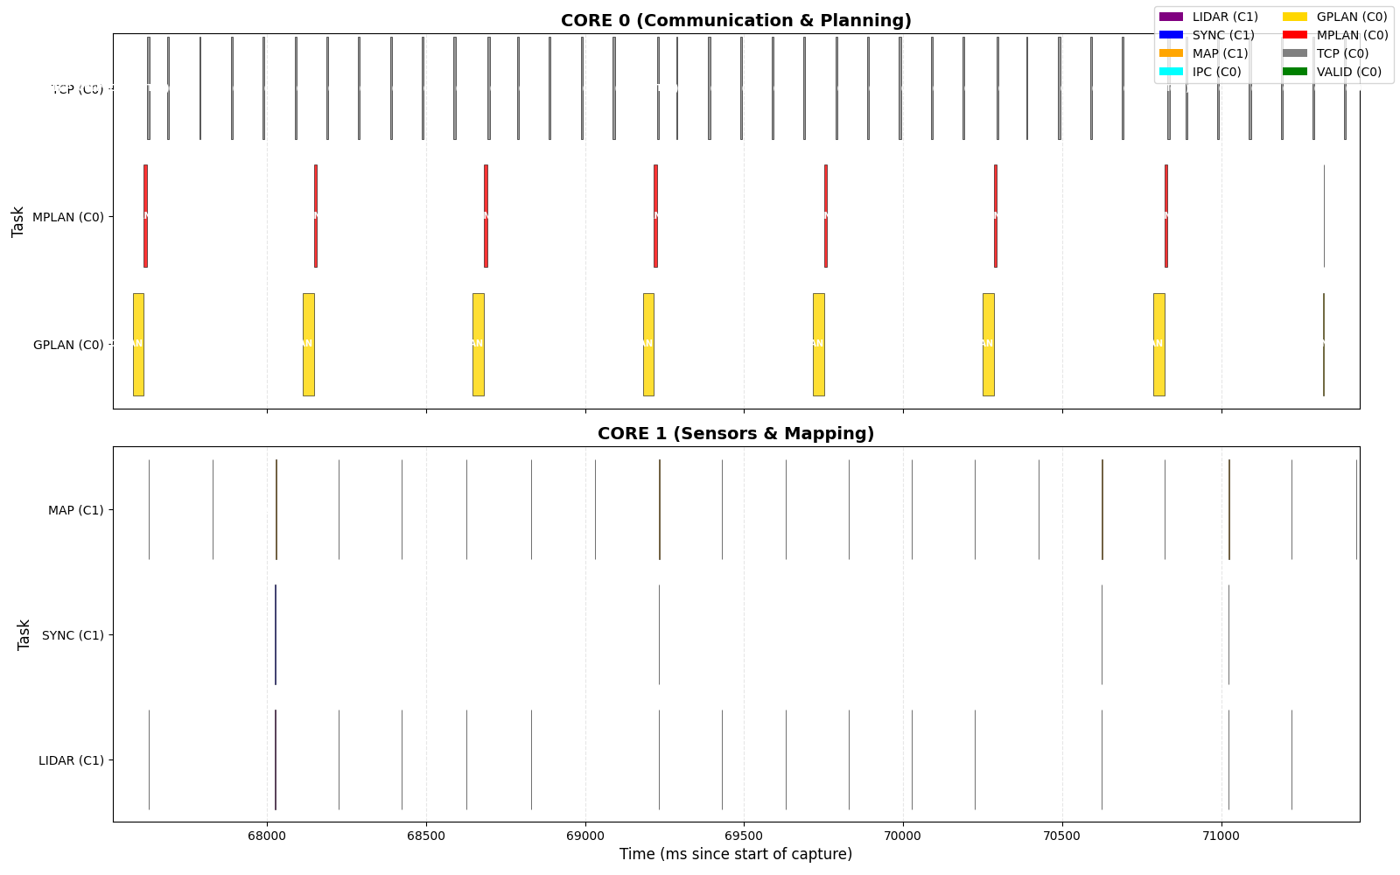
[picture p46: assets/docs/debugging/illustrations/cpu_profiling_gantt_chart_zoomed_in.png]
Gantt Chart


Generated by `plot_trace.py` - shows longer time periods with precise timing:

- X-axis: Time in milliseconds
- Y-axis: Tasks grouped by core
- Each bar shows exact start/end times
- Labels appear on bars >1ms wide

## Files

### Core System
- `main_esp1.cpp` - Task implementations + trace logging
- `data_types.h` - TaskEvent struct definition
- `ground_station.py` - Live visualization + CSV logging
- `plot_trace.py` - Offline Gantt chart generation

---

**Last Update**: December 2025

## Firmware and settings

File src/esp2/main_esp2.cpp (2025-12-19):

#include <Arduino.h>
#include <WiFi.h>

// 1. Configuration & Global State
#include "config.h"
#include "global_state.h"

// 2. Hardware Interfaces (Required for .begin() calls)
#include "hardware/I2C_wire.h"
#include "hardware/I2C_mutex.h"
#include "hardware/MotorManager.h"
#include "hardware/DMS15.h"
#include "hardware/UltraSonicSensor.h"
#include "hardware/ImuSensor.h"
#include "hardware/EncoderCarVelocity.h"
#include "common/esp_link.h"

// 3. Task Definitions (Required for xTaskCreate)
#include "tasks/task_motor.h"
#include "tasks/task_ultrasonic.h"
#include "tasks/task_odometry.h"
#include "tasks/task_pure_pursuit.h"
#include "tasks/task_receive_path.h"

// Task Handles
TaskHandle_t motorTask, ultrasonicTask, pursuitTask, odomTask, receiveTask;

//Protect variables used in multiple tasks
SemaphoreHandle_t poseMutex = nullptr;
SemaphoreHandle_t pathMutex = nullptr;
SemaphoreHandle_t stateMutex = nullptr;

void setup() {
    Serial.begin(115200);
    delay(2000);

    pinMode(LED_BUILTIN, OUTPUT);
    digitalWrite(LED_BUILTIN, HIGH); 

    poseMutex = xSemaphoreCreateMutex();
    pathMutex = xSemaphoreCreateMutex();
    stateMutex = xSemaphoreCreateMutex();

    if (!poseMutex || !pathMutex || !stateMutex) {
        Serial.println("Mutex creation failed!");
        while(1);
    }

    // --- Hardware Init ---
    I2C_wire.begin(Config::SDA_PIN, Config::SCL_PIN);
    i2cMutexInit();
    esp_link.begin();

    if (!servo_dir.begin()) { Serial.println("Servo init failed!"); while (true); }
    else { Serial.println("Servo initialized"); }
    servo_dir.setAngle(Config::STRAIGHT_ANGLE);
    
    if (!ultrasonic.begin()) { Serial.println("WARNING: US init failed"); } 
    else { Serial.println("Ultra Sonic initialized"); }
    
    if (!imu.begin()) { Serial.println("IMU init failed!"); vTaskDelete(NULL); return; }
    else { Serial.println("IMU initialized"); }
    
    if (!encoder.begin()) { Serial.println("Encoder init failed!"); while (true); }
    else { Serial.println("Encoder initialized"); }
    
    if (!motor.begin()) { Serial.println("Motor init failed!"); while (true); }
    else { Serial.println("Motor initialized"); }

    Serial.println("---- Initialization complete. ----");

    // delay(500);
    // digitalWrite(LED_BUILTIN, LOW); // Turn off built-in LED

    // --- FreeRTOS Tasks Creation ---
    xTaskCreatePinnedToCore(TaskReceivePath,            "RX_Path",       6144, NULL, 3, &receiveTask,    0);
    xTaskCreatePinnedToCore(TaskOdometryUnified_Stable, "Odom",         10240, NULL, 3, &odomTask,       0);
    xTaskCreatePinnedToCore(TaskMotor,                  "Motor",         6144, NULL, 2, &motorTask,      1); 
    xTaskCreatePinnedToCore(TaskUltrasonic,             "Ultrasonic",    6144, NULL, 2, &ultrasonicTask, 1); 
    xTaskCreatePinnedToCore(TaskPurePursuit,            "PurePursuit",   6144, NULL, 1, &pursuitTask,    1); 


    digitalWrite(LED_BUILTIN, LOW); // Turn off built-in LED
    delay(200);
    digitalWrite(LED_BUILTIN, HIGH); // Turn off built-in LED
    delay(200);
    digitalWrite(LED_BUILTIN, LOW); // Turn off built-in LED
    delay(200);
    digitalWrite(LED_BUILTIN, HIGH); // Turn off built-in LED
    delay(200);
    digitalWrite(LED_BUILTIN, LOW); // Turn off built-in LED
}

void loop() { 
    // Main loop is empty because all operations are handled in FreeRTOS tasks
    // Once the taks are created in setup(), they run independently
}

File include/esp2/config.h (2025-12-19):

/**
 * @file config.h
 * @brief Central configuration for ESP2 - all pins, constants, and parameters
 */

#pragma once
#include <cstdint>

namespace Config {
    // ===================================================================
    // HARDWARE PINS
    // ===================================================================
    constexpr uint8_t ESC_PIN = 15;
    constexpr uint8_t SERVO_DIR_PIN = 6;
    constexpr uint8_t US_TRIG_PIN = 5;
    constexpr uint8_t US_ECHO_PIN = 19;
    constexpr uint8_t SDA_PIN = 8;
    constexpr uint8_t SCL_PIN = 9;

    // ===================================================================
    // CONTROL PARAMETERS
    // ===================================================================
    constexpr float MOTOR_POWER_DRIVE = 0.18f;      // 18% throttle
    constexpr float EMERGENCY_DISTANCE = 0.30f;     // meters
    constexpr float GOAL_TOLERANCE = 0.05f;         // 5 cm
    constexpr int STRAIGHT_ANGLE = 90;              //writing 90 degrees into the front wheels servo = straight
    
    // ===================================================================
    // TASK TIMING (milliseconds)
    // ===================================================================
    constexpr uint32_t MOTOR_UPDATE_MS = 20;        // 50 Hz
    constexpr uint32_t ULTRASONIC_UPDATE_MS = 200;  // 5 Hz (slow sensor)
    constexpr uint32_t ODOMETRY_UPDATE_MS = 10;     // 100 Hz
    constexpr uint32_t PURSUIT_UPDATE_MS = 20;      // 50 Hz
    constexpr uint32_t PUBLISH_INTERVAL_MS = 200;   // MQTT rate
    constexpr uint32_t DIAGNOSTICS_INTERVAL_MS = 3000; // 3 seconds

    // ===================================================================
    // WIFI & TCP
    // ===================================================================
    constexpr const char* WIFI_SSID = "LIDAR_AP";
    constexpr const char* WIFI_PASSWORD = "l1darpass";
    constexpr uint16_t TCP_PORT = 9000;
}

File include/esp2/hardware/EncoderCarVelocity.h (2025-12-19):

/**
 * @file EncoderCarVelocity.h
 * @brief Interface for measuring car velocity and position using AS5600 magnetic encoder.
 * 
 * This class provides methods to read motor and wheel angular/linear velocities,
 * as well as cumulative distance traveled. It interfaces with the AS5600 encoder
 * via I2C and accounts for gear ratio and wheel dimensions.
 * 
 * @note Requires the AS5600 library (https://github.com/RobTillaart/AS5600) and I2C_wire configuration.
 * @note getDistance() must be called at 100+ Hz for accurate cumulative position tracking.
 * 
 * @author SLAMaleykoum 
 * @date Nov 2025
 */

#ifndef ENCODER_CAR_VELOCITY_H
#define ENCODER_CAR_VELOCITY_H

#include <AS5600.h>
#include "I2C_wire.h"

#define GEAR_RATIO 10.0f     // Motor to wheel gear reduction ratio (10:1) 
#define WHEEL_RADIUS 0.0495f // Wheel radius in meters //maybe needs to be adapted but 9.9 diametre  

/**
 * @class EncoderCarVelocity
 * @brief Manages velocity and position measurements from AS5600 magnetic encoder.
 * 
 * Provides real-time measurements of motor/wheel speeds and cumulative distance.
 * Uses AS5600's cumulative position tracking for accurate odometry.
 */
class EncoderCarVelocity {
public:
    /**
     * @brief Constructs an EncoderCarVelocity object.
     */
    EncoderCarVelocity();

    /**
     * @brief Initializes the AS5600 encoder and I2C communication.
     * 
     * Configures the encoder for clockwise rotation with noise filtering.
     * Must be called before using any measurement functions.
     * 
     * @return true if encoder is detected and initialized successfully, false otherwise.
     */
    bool begin();  

    /**
     * @brief Gets the motor shaft angular velocity.
     * 
     * Reads the instantaneous angular speed directly from the AS5600.
     * 
     * @return Motor angular velocity in radians per second.
     * 
     * @note library handles delta / dt internally
     */
    float getMotorAngularVelocity() {return as5600.getAngularSpeed(AS5600_MODE_RADIANS, true);}
    

    /**
     * @brief Gets the wheel angular velocity (accounts for gear ratio).
     * 
     * Converts motor speed to wheel speed using GEAR_RATIO.
     * 
     * @return Wheel angular velocity in radians per second.
     */
    float getWheelAngularVelocity() {return getMotorAngularVelocity() / GEAR_RATIO;} 
    
    /**
     * @brief Gets the linear velocity of the car.
     * 
     * Converts wheel angular velocity to linear velocity using wheel radius.
     * This is the actual speed at which the car is moving.
     * 
     * @return Linear velocity in meters per second.
     */
    float getWheelLinearVelocity() {return getWheelAngularVelocity() * WHEEL_RADIUS;}
    
    /**
     * @brief Gets the raw cumulative position from AS5600.
     * 
     * Returns the total encoder ticks accumulated since initialization.
     * Used internally by getDistance() for precise position tracking.
     * 
     * @return Cumulative position in encoder ticks (int32_t).
     */
    int32_t getCumulativePosition() {return as5600.getCumulativePosition();}

    /**
     * @brief Calculates the total distance traveled by the car.
     * 
     * Accumulates distance based on encoder tick changes between calls.
     * Returns cumulative distance since begin() was called.
     * 
     * Process:
     * 1. Reads current cumulative position from AS5600
     * 2. Calculates incremental ticks since last call
     * 3. Converts ticks -> motor rotations (4096 ticks/rev)
     * 4. Converts motor rotations -> wheel rotations (÷ gear ratio)
     * 5. Converts wheel rotations -> linear distance (× wheel circumference)
     * 6. Accumulates into total distance traveled
     * 
     * @note Must be called at 100+ Hz for accurate tracking per AS5600 requirements.
     * @note This function maintains internal state and accumulates over time.
     * 
     * @return Total distance traveled in meters since begin() was called (cumulative).
     */
    float getDistance();

private:
    AS5600 as5600 = AS5600(&I2C_wire); // AS5600 encoder instance

    int32_t lastCumTicks = 0; // Previous cumulative tick count
    float wheelDistanceMeters= 0.0f;  // Accumulated distance in meters;
};

#endif

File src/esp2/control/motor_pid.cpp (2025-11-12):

// Filename: esp2/control/motor_pid.cpp
// Description: Implementation of the high-frequency PID motor control loop on ESP_2.

// Note: our car only has one motor, so our pid will have as input the target
//      and current velocity of the car, and output the pwm value for the motor.
//      To check the current velocity of the car we use the odometry data from
//      the motor enocoder, and to get the target velocity we use the output from
//      the pure pursuit controller.

//      The motor controller runs in the highest priority task (100-200 Hz).

// For manual testing, we can set the target velocity to a constant value
//      and see how well the PID controller maintains that velocity.
//      If we set the target velocity for a fixed time we can check the distance
//      traveled by the car to verify the velocity control. By setting the target
//      velocity to different values we can also test the responsiveness of the
//      controller.
//      If we set the target velocity to zero, we can test the braking performance
//      of the car. 

// NOTE that the breaking performance could potentially be better if instead of
//      just setting the motor pwm to zero, we actively reverse the motor in bursts
//      to decelerate faster. This could be implemented in the emergency_stop()
//      function.


#include "motor_pid.h"

MotorPID::MotorPID(float Kp, float Ki, float Kd)
    : Kp_(Kp), Ki_(Ki), Kd_(Kd) {
    reset();
}

void MotorPID::reset() {
    integral_ = 0.0f;
    prev_err_ = 0.0f;
}

MotorOutputs MotorPID::compute_pwm_output(const Velocity& target_vel, const Velocity& current_velocity, float dt) {
    
    // Prevent division by zero or negative time
    if (dt <= 0.0f) {
        return NEUTRAL_US; // Return neutral if time has not advanced
    }

    // Calculate Error
    float e = target_vel.v_linear - current_velocity.v_linear;

    // Calculate Integral (with anti-windup)
    integral_ += e * dt;
    integral_ = constrain(integral_, PID_INTEGRAL_MIN, PID_INTEGRAL_MAX);

    // Calculate Derivative
    float derivative = (e - prev_err_) / dt;

    // Compute full PID control signal (scaled -1.0 to 1.0)
    float control_signal = (Kp_ * e) + (Ki_ * integral_) + (Kd_ * derivative);

    // Store error for next iteration
    prev_err_ = e;

    // Clamp the control signal
    return constrain(control_signal, PID_CONTROL_MIN, PID_CONTROL_MAX);
}

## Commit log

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2025-10-17 Sensors/skeleton: First draft of the skeleton for sensor data collection.
    At this point we're still defining the architecture of the project. Mainly how we're going to comunicate between the "blocs" (or nodes if we decide to use microROS and ROS2)
    These files shouldn't change much since either way, there should be a wrapper for communication, but depending on how it's done and unforseen implementation choices the types or public methods could 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
2025-10-20 architecture/pipeline: Add documentation for skeleton (issue #15)
    This commit formalizes the system's architecture by introducing documentation for the full data pipeline.
    The documentation includes:
    - `README.md`: High-level project overview and architecture summary. (TO BE UPDATED AND COMPLETED)
    - `esp1/README.md`: Detailed breakdown of the **Global SLAM (EKF_SLAM)**, **Bayesian Occupancy Grid**, and **A\* Planning** processes on the ESP-1.
    - `esp2/README.md`: Flow of the **Real-Time Control** tasks on the ESP-2, including the **EKFLocalizer**, **Pure Pursuit**, and **PID loop**.
    The architecture diagram (`docs/global-architecture-2.png`) is also now referenced for visual context.
2025-10-22 Created manual_control_test branch for manual car control
    Reorganized structure of esp2 to be compatible with PlatformIO.
    - Integrated and modified code from the previous group related to hardware components: motor, ultrasonic sensor, and servo
    - Added new files to support manual control functionality without using ROS
    - Created a new main program for manual car operation
    - Will have to test the code with the car
2025-10-26 Completing with the code for AS5600 encoder + IMU
    Adapt the code from the previous group
2025-10-26 Adding tests files
    New test files and easier way to make new ones.
    There is now a directory test inside of src, containing 2 global files named test_common.h and test_globals.cpp, and cpp files for precise tests. To add new test :
    - Add a new file inside src/test/ with a precise name on whwt will be tested
    - Add the name of setup_... and loop_... functions in the test_common.h file
    - Add an ID with the corresponding setup and loop function in the test_main.cpp (follow the same pattern as already present)
    To run them :
    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
2025-10-27 Wifi and MQTT connection
    Added the "WiFi.h" and "PubSubClient.h" in main.cpp and the lib deps of PubSubClient in platformio.ini.
    In the main, 3 new functions :
    setupWifi() : to connect the ESP32 to the wifi of the computer (change the ssid and the pass values)
    reconnect() : for the ESP to establish the MQTT connection with the broker given
    callback(topic, payload, length) : to catch the messages we send from the MQTT broker
    A small test has been added in main.cpp (can be remove after)
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2025-10-31 Correction of the Wifi connection
    Passed the WiFiClient by reference in the Connection constructor in order to have only one object
    Added mqtt_client.py, the file to connect to the MQTT broker in order to get some datas and debug (especially the Lidar data)
    [wifi_connection.cpp]
2025-10-31 ESP1 tests and mqtt_client adaptation
    Copied some files of ESP2 to ESP1 to be able to test the LiDAR. One small "fake" test with some random data to show it on the MQTT broker with the python file "mqtt_client.py".
    [wifi_connection.cpp]
2025-11-01 Small changes in mqtt_client and the basic test for the lidar
    mqtt_client.py adapted only for the LiDAR.
2025-11-02 esp2/control/motor_pid: First version of the velocity PID for the dc motor.
    first version of the `MotorPID` class, which is
    responsible for closed-loop velocity control of the drive motor.
    Key features:
    - Takes `target_vel` and `current_vel` as input.
    - Computes P, I, and D terms based on time-delta (`dt`) for stable control.
    - Includes integral anti-windup protection by clamping the integral term.
    - Directly outputs a `MotorOutputs` (uint16_t) PWM pulse width
    (e.g., 1000-2000µs), scaled for the ESC.
    // TODO: CHANGE THIS ONCE WE TEST ON THE CAR!!!
    - Provides a `reset()` method to clear the controller's internal state.
    [motor_pid.cpp, motor_pid.h]
2025-11-03 esp2/control/motor_pid_readme: Documentation First draft of the concept of a PID controller and explication of the motor's PID implementation. Qwick explication of how to use it in the main code.
2025-11-05 Created EncoderCarVelocity to compute the car's velocity
    - Worked on the AS5600 encoder
    - Reused previous group's code to read motor angles and then of the wheel thanks to the ratio
    - Created EncoderCarVelocity module to compute
    -Rotational speed of the moto and wheels
    -Linear velocity of the car
2025-11-05 Small fixes for the files related to the car velocity
    [EncoderCarVelocity.cpp, EncoderCarVelocity.h]
2025-11-08 Fixed EncoderCarVelocity + PID test
    - Only be used to measure the car's current velocity.
    - Delays need to be tested to be sure that the measurements are accurate.
    - Test create for PID to tune it
    [EncoderCarVelocity.cpp, EncoderCarVelocity.h]
2025-11-09 common/transforms: Add Transforms library for coordinate frames (#45)
    Introduces a header-only library (`transforms.h`) for 2D coordinate transformations.
    - Defines a clear robot coordinate system: X-Right, Y-Forward, with theta as CCW rotation from global X.
    - Provides `Transforms::to_robot_frame()` to convert global points to robot-centric.
    - Provides `Transforms::to_global_frame()` to convert robot-centric points to global.
    - Functions are `inline` and modify waypoints in-place for efficiency.
2025-11-09 esp2/control/pure-pursuit: Add PurePursuit path tracking controller (#33)
    Implements the Pure Pursuit algorithm for lateral control with documentation.
    - Calculates adaptive lookahead distance (Ld) based on velocity.
    - Finds a target waypoint on the path at the lookahead distance.
    - Transforms the global target point to the robot-centric frame (X-Right, Y-Fwd) using the `Transforms` library.
    - Computes the target steering angle (delta) using the bicycle kinematic model: delta = atan2(2 * L * x_lateral, Ld^2).
    - Calculates an adaptive target speed, slowing down for sharper turns.
    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
2025-11-09 folder structure: Move motor_pid.cpp to esp2/control/ While talking with Blanche, I realised the file `motor_pid.cpp` should acutally be in `esp2/control/` hence the move of file to the new location.
    checkout original motor_pid commit: c1306dc2227a419532f44f018677c4354cd8f6e1
2025-11-12 Add AS5600 library and update velocity handling
    - Integrated AS5600 library for encoder angle readings
    - Updated EncoderCarVelocity to compute linear velocity using gear ratio and wheel radius
    - Applied quick fixes to motor_pid
    - Added two new tests: path_pid and pid_velocity
    - Minor code cleanup and small bug fixes
    [EncoderCarVelocity.cpp, EncoderCarVelocity.h, motor_pid.cpp]
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2025-11-14 Wifi Connection fix + communication between esps
    commit 66f1e9e4f8d1a110259c4f276a042e703a870100
    Date: Fri Nov 14 15:50:21 2025 +0100
    Connection modified
    Add a parameter "clientId" so that esp1 and esp2 have 2 different id when they connect
    commit 30540549d6108cbde395fec70a85f7953937dd47
    Date: Fri Nov 14 15:49:29 2025 +0100
    corrected test, this should work better
    commit 93be30eb7fab86996f349c6dfb270a497520f390
    Date: Fr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
    [wifi_connection.cpp]
2025-11-14 esp2/control/pure-pursuit: Update Disabled the adaptive speed and lookahead distance since our PID doesn't work because of the ESC's limitations (As of today: 14 Nov. 2025).
    Set the max steering angle of the car (we can probably go further, but we don't want to force the servos).
    Even tho it's not currently useful, set the min and max speeds we actually want to go.
    [pure_pursuit.h]
2025-11-14 esp2/control/pure_pursuit: Fix Forgot to change parameters for fixed valued update.
    [pure_pursuit.h]
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2025-11-14 esp2/control/pure_pursuit.h: Fix Make the constructor default.
    [pure_pursuit.h]
2025-11-17 pure-pursuit: Fix stopping after reaching the goal bug
    [pure_pursuit.h]
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2025-11-22 CAD files: Upgrade (#57) Since we were already re-doing all the wireing we decided to redo the casing for the car to make it a bit nicer. Just a little upgrade ;)
    _Note to self: CAD files take much more time than expected._
    (Perfect design on the first go tho !)
    [MIT_car_body.stl, MIT_roof.stl]
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2025-11-26 Fixes and add ons to improve position, odometry and tests
    [EncoderCarVelocity.cpp, main_esp2.cpp, pure_pursuit.h]
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2025-11-28 Pure Pursuit: Enforce forward tracking and add off-path recovery (#43)
    - Implemented "Greedy Forward Search": The lookahead loop now iterates through all segments to find the valid intersection with the highest index, preventing the car from locking onto path segments behind it.
    - Added "Magnet Logic" fallback: If the car is further than the lookahead distance from the path (no intersection found), the algorithm now targets the closest point on the path instead of the final goal. This prevents cutting corners when drifting wide.
    [pure_pursuit.h]
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2025-11-29 Added test + small fixes for i2c
    [EncoderCarVelocity.cpp]
2025-11-29 Revert "Updated ESP2 main for receiving GlobalPathMessage from ESP1"
    This reverts commit 2e26354b2ece2db7d9b84fcc6b88ec39d7060080, reversing
    changes made to 7b42c4b212559baa60c3ef85fcdd5240f97b7ab7.
    [main_esp2.cpp]
2025-11-29 Restoring stable state from my-working-version
    [MIT_car_body.stl, MIT_roof.stl, rc_car_telemetry.csv]
2025-11-29 Re-applying my specific features (#61) on top of stable code
    [rc_car_telemetry.csv]
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2025-12-01 main_esp2: refactor main, introduce global_state & config, reorganize include structure (#60)
    Refactored ESP2 structure to clean up main_esp2.cpp
    - Created global_state.h/.cpp for all shared hardware instances, pose
    variables, and flags
    - Added config.h to consolidate pins, thresholds, and task intervals.
    - Reorganized include/esp2 into hardware/, control/, localization/ for clearer module separation.
    - Updated all include paths accordingly.
    - Fixed main_esp2.cpp accordingly to previous modificatons
    - Fixed ESP2 test files that were redefining globals and causing
    multiple-definition linker errors.
    [EncoderCarVelocity.cpp, EncoderCarVelocity.h, MotorController.cpp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]
2025-12-02 modifications for lidar and bayesian (blanche work) + first push of the main
    - tests are working but some problems occure in the plot of bayesian grid -> the points are always getting clearer and never going back black if a new object is detected
    - main is implemented for lidar and bayesian but not for the global planner and mission planner
    [lidar.cpp]
2025-12-02 main_esp2 (#60): modularize main task logic into separate files
    - Split `main_esp2.cpp` into dedicated task modules under `src/esp2/tasks/`.
    - Created separate headers and source files for Motor, Ultrasonic, Odometry, PurePursuit, and PathReceive tasks.
    - Cleaned up `main_esp2.cpp` to focus solely on hardware initialization and task spawning.
    - Added necessary hardware includes to task files to resolve "incomplete type" compilation errors.
    - Updated `global_state` usage to ensure correct linkage across modules.
    [global_state.cpp, main_esp2.cpp, task_motor.cpp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]
2025-12-03 main_esp2: (#60) Remove TCP stuff Since the esp2 doesn't use TCP, it was only used for debugging purpuses, it is now gone. The whole of the debugging will now take place on the esp1.
    [global_state.cpp, main_esp2.cpp, task_motor.cpp]
2025-12-03 main_esp2: (#60) Missed this file in last commit
    [pure_pursuit.h]
2025-12-06 main_esp1: Version 1 of the ESP1 main (#55)
    Fixing critical bug where WiFi and Lidar didn't startup.
    The bug: Bayesian grid is too large. Even tho there are still big bugs in the `main_esp1.cpp` file, we can reliably use it to test our code.
    We're now testing Anas's version of the Bayesian grid.
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2025-12-06 ground_station.py: Fix points must be pairs (#63) Used to crash frequently giving "Error: points must be number pairs".
    This fix filters out nan values and only sends the data if there are two valid points.
    We don't care of missing one or two points since there are so many and it's only for visual purpuses.
2025-12-07 ESP2 Main : firstPathReceive + fixes (#60)
    - Introduced global variable `firstPathReceived` (initialized to false in global_state.cpp).
    It is set to true in TaskReceivePath once ESP2 receives its first path from ESP1.
    Used in task_motor.cpp to ensure the car only starts moving after a path is received.
    - Initialized `receivedPath` to {0} in global_state.cpp.
    - Applied a minor fix in task_ultrasonic.cpp.
    [global_state.cpp, task_motor.cpp]
2025-12-07 Bayesian Grid: FIX - map rotation and vertical flip (#62 / #29) - Updated `bayesian_grid.cpp` to correctly align the occupancy grid with the robot's North-Up frame. - Added a 90-degree offset to `pos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
2025-12-08 main_esp1: Optimisation for Mission Planner (#64)
    The mission planner is too heavy. Big changes for debugging purpuses. Will be usefull either way.
    New:
    - Run-Length Encoding for the map
    - Got rid of the Mutex blocking the map to allow reads from other tasks so we can still stream (worst case senario, there's a missmatch from one version prior and one version later of the map)
2025-12-08 Mission Planner: Fix Logic and Refactor (#64) !! Work with @anaselmadhi, @yolosunflo and @alexdorsaz !!
    - Fixed "Startup Suicide" bug in `MissionPlanner::update_goal`:
    - Planner now uses a `patience_counter` to wait for valid map data instead of immediately switching to `RETURN_HOME`.
    - Implemented Local-to-Global search fallback: scans ±6m first, then full map if no frontiers found locally. This might not be the best. (tbd)
    - Refactored Frontier Detection:
    - Extracted BFS clustering into private `search_for_candidates` helper to support dual-pass search.
    - Added edge filtering to ignore map borders as valid frontiers.
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2025-12-11 first working version of global planner !!!
    The car moves autonomously and avoids the obstacles.
    Pb: it loses its position at some point..
    [global_state.cpp]
2025-12-12 almost working version
    Pb:
    - lidar crashes after a certain time, possibly because of a maneuver
    - the values of the global path overflow on y about a certain time too.
    - the connection to the tcp is way too long from my computer, sometimes i can't even see the map before it stops working. Maybe this is just an issue from my computer.
    The display of the map is good, the resolution is of 0.4 on a map of 25*25 so it maps a zone of 10m per 10m.
    The goal is well updated depending on the frontiers.
    The global is also updating correctly, generating a new path when the previous is reached, or the map has been discovered around the goal.
    [config.h, global_state.cpp, lidar.cpp]
2025-12-12 Integration hell: (#69) optimize planner logic, fix A* underflow, correct coordinate alignment
    - Modified `MissionPlanner::update_goal` to use lazy evaluation (`is_current_goal_valid`), significantly reducing CPU load by avoiding BFS re-scans when the current goal remains valid.
    - Fixed "Startup Panic" logic in Mission Planner: added a guard clause to wait if the robot is currently on an "Unknown" cell (map not ready), preventing premature switching to `RETURN_HOME`.
    - Fixed critical buffer underflow in `GlobalPlanner::generate_path` where `plen == 0` (Start == Goal) caused access to negative array indices; added explicit handling for 0-length paths.
    - Updated `grid_to_world` in `common/util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
    [task_odometry.cpp]
2025-12-12 Lidar Data Handleing (#69): Ping-Pong Optimisation pointer queues - Implemented "Ping-Pong" Double Buffering for Lidar-to-Map synchronization. Replaced `SyncedScan` pass-by-value queues (which caused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
2025-12-13 Optimisation (#69): optimize A* performance and stability
    - Implemented "Greedy A*" strategy by increasing the heuristic weight (h * 3). This biases the search towards the goal, significantly reducing the number of nodes explored and execution time.
    - Added Task Yielding (`vTaskDelay(1)`) every 50 iterations within the A* loop. This prevents the Task Watchdog Timer (TWDT) from resetting the ESP32 during complex pathfinding operations... This might actually be usefull to do in other computationally heavy areas.
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2025-12-13 Revert "Ground Station: (#63 / #82) Logger update"
    This reverts commit 777b44f1b3073715c0eb8df9c6d28198f97c9a53.
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2025-12-14 Github page Issue #6 : Created assets folder
    - Moved the CAD, Images folder into it and create a Demo and circuit folder.
    - Added the updated electrical diagram to the circuit folder#74
2025-12-14 Github page : moved docs folder into assets folder
    [MIT_car_body.stl, MIT_roof.stl]
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2025-12-14 Github page : README and CAD update
    - Added TurboSLAM's CAD files related to the ultrasonic sensor and the encoder
    - updated the main readme and the one of the CAD files accordingly
    - added a video showing how the body and the roof of the car interlock
    [bumper_and_carattach.stl, encoder_support.stl, ultrasonicsensor_case.stl]
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2025-12-15 Github page : Fixed wrong stl files and updated README
    [bumper_and_carattach.stl, ultrasonicsensor_case.stl]
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2025-12-15 ESP2 task motor creneau Issue #72
    Added a recovery file that turns the car around according to the location of the first coordinate headed towards the goal, but still needs refining
    [recovery_maneuvers.cpp]
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2025-12-15 ESP2 Main : fixes in the task where no protective mutexes had been applied for free rtos
    [main_esp2.cpp, task_motor.cpp, task_odometry.cpp]
2025-12-15 modifications in main_esp1
    lidar with the functions before
    mission_planner changed the cluster min size to 8
    global_planner updated as before because the new version doesn't work
    [lidar.cpp]
2025-12-16 ESP2 tasks + archive, recovery
    - Quick fixes for the tasks since now the recovery is implemented
    - added the old recovery version into archive since we use the simpler version that doesn't turn the car around facing the next waypoint
    - updated the archive in README for recovery
    [recovery_maneuvers.cpp, task_motor.cpp, task_odometry.cpp]
2025-12-16 Goal changes when not accessible
    PB:
    - Works one time out of 10 lol
    - path takes way too much time to be computed
    [recovery_maneuvers.cpp]
2025-12-17 Better parallelism
    Big bugs:
    Path is not updated
    Esp1 crashes (maybe due to lo battery)
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2025-12-18 clean and all but still crashing
    esp1 crashes but we don't get why
    [task_motor.cpp]
2025-12-18 documentation updates
    -clearer documentation for lidar.h with the final version used
    -updated readme for pure_pursuit
    -cleaned readme for esp2 (shorter for pure_pursuit and added recovery maneuver
    -updates in the main readme (conclusion, problems, table of contents)
    [lidar.cpp]
2025-12-19 Github documentaiton
    [MIT_car_body.stl, MIT_roof.stl, bumper_and_carattach.stl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]
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
